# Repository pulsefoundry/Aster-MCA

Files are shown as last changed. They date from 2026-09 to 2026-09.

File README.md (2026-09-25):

# Aster MCA

[简体中文](README.zh-CN.md)

Aster MCA is a compact, USB-powered 4096-channel pulse-height analyzer for
already-amplified detector signals. It combines a 12-bit 10 MSPS ADC, a Gowin
GW1N-4 FPGA, and a CH347T USB/JTAG/UART bridge on one 90 mm × 70 mm four-layer
board.

> **Prototype status:** revision 0.1 has acquired a repeatable Cs-137 spectrum
> from an amplified NaI(Tl)/PMT probe, but the published as-built hardware has
> three mandatory assembly notes. Do not order or assemble the v0.1 production
> package unchanged. See [Hardware errata](docs/hardware-errata-v0.1.md).

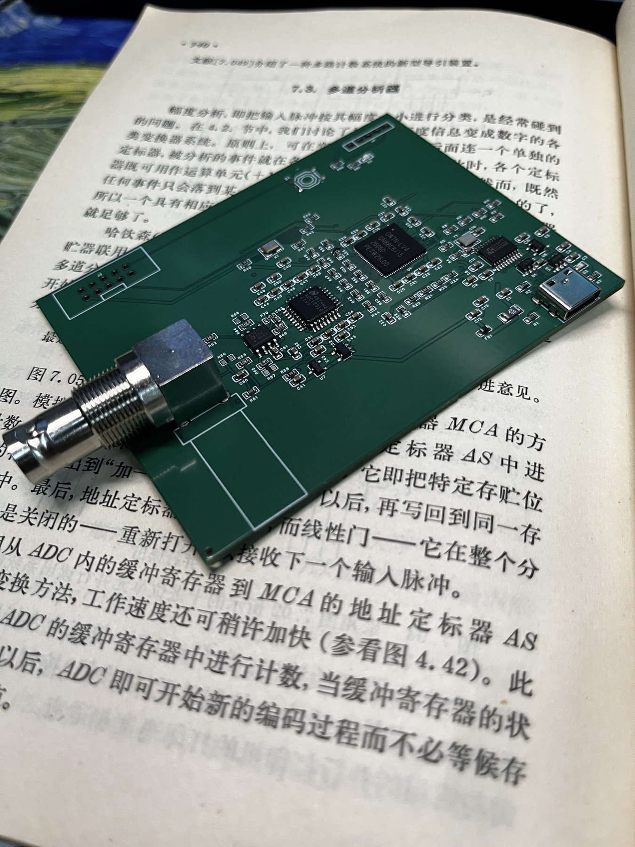
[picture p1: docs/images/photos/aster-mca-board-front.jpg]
Assembled Aster MCA v0.1 prototype board


*Assembled and physically validated v0.1 prototype.*

## What works

- ADC12010 parallel capture at 10 MSPS.
- FPGA baseline tracking, threshold detection, peak-height extraction, pulse
  rejection, saturation recovery, and a 4096 × 32-bit histogram.
- USB communication on macOS through the on-board CH347T and libusb; no serial
  driver or external programmer is required.
- Volatile SRAM configuration over the same USB-C connector.
- Live diagnostics for ADC min/max/baseline, triggers, accepted/rejected and
  saturated events, histogram drops, live samples, and UART errors.
- Repeatable source-versus-background separation on the first repaired boards.

The current physically validated firmware is **v1.9**. It keeps the proven v1.3
MCA algorithm but moves all 12 ADC inputs into dedicated falling-edge IOLOGIC
registers, followed by a full-cycle fabric pipeline stage. Two independently
placed images now produce matching Cs-137 spectra. FPGA configuration is
volatile and must be reloaded after power loss.

## Aster MCA v2.0 concept

The repository also contains a routed, explicitly unreleased
[v2.0 high-performance concept](hardware/rev2.0-preliminary/README.md): a
16-bit 40 MSPS ADS5560, Intel MAX 10 FPGA, directly soldered RP2350 host module,
and three fixed analogue ranges of approximately 0.5x, 5x and 25x. The current
r8 CAD passes ERC, DRC and an independent 489-pin network audit, and its THS4551
front end has reproducible analogue simulations.

v2.0 has no FPGA firmware or physical prototype yet. Its manufacturing files
are published for review and quotation only and must not be treated as a
production release.

## Prototype photographs

| Powered bench prototype | Second PCB during assembly and inspection |
| --- | --- |
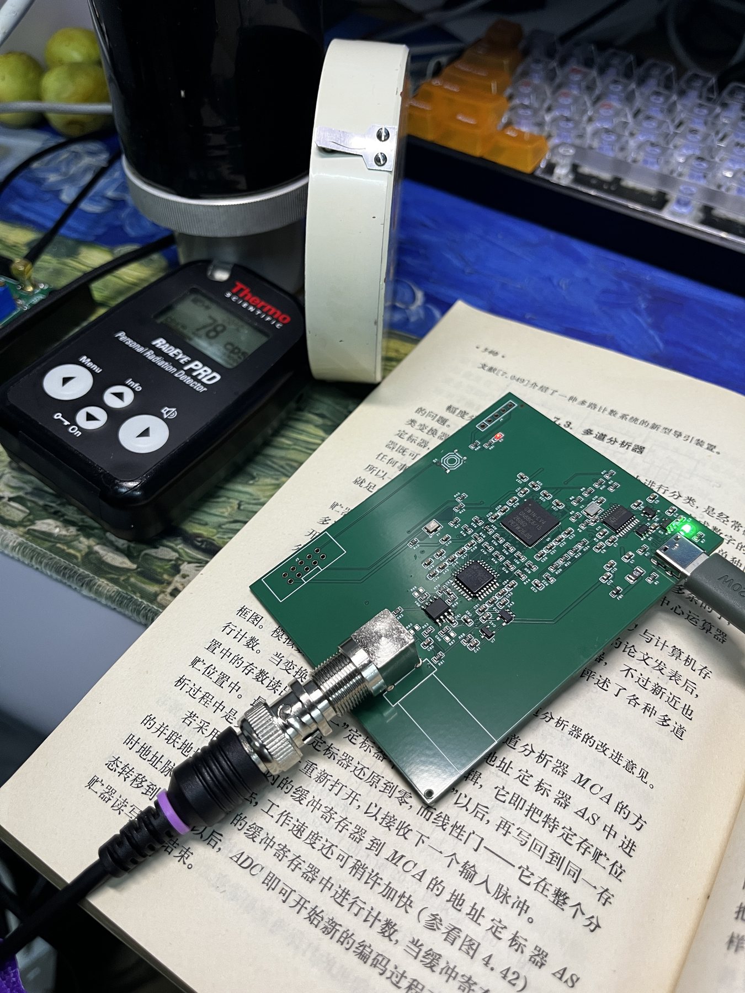
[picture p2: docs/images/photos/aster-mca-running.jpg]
Powered Aster MCA prototype
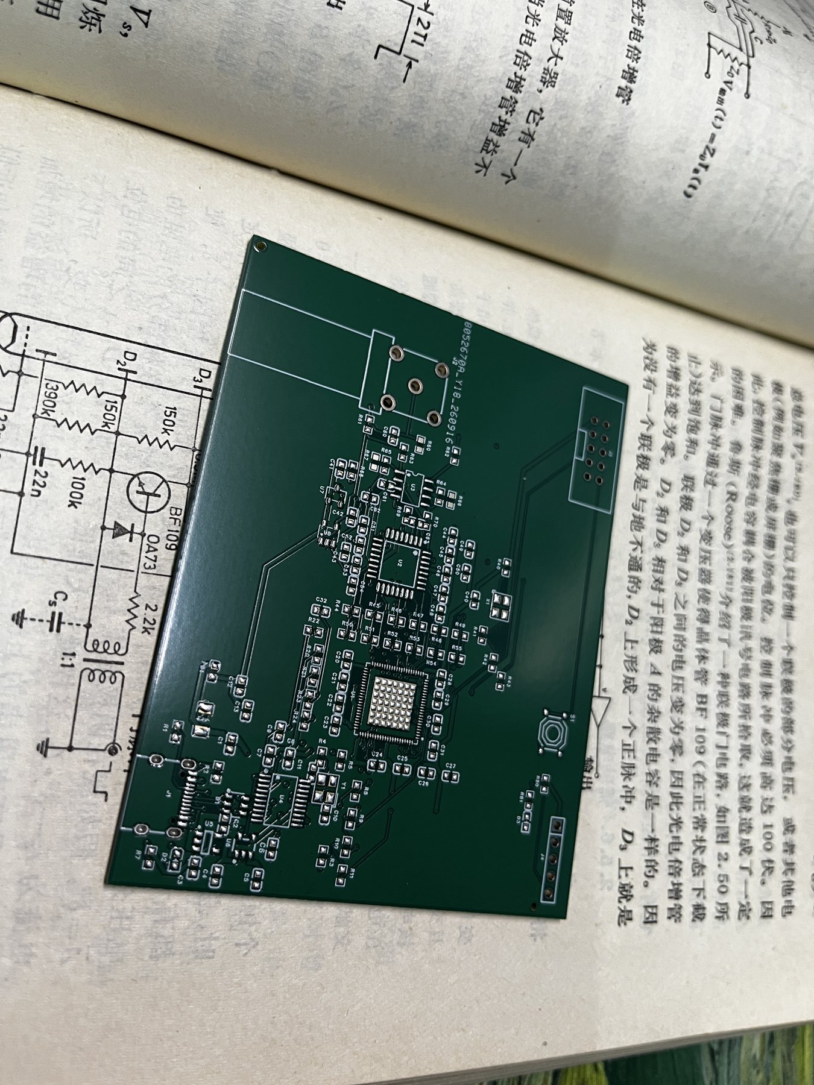
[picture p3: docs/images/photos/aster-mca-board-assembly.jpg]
Second Aster MCA PCB during assembly
|  |  |

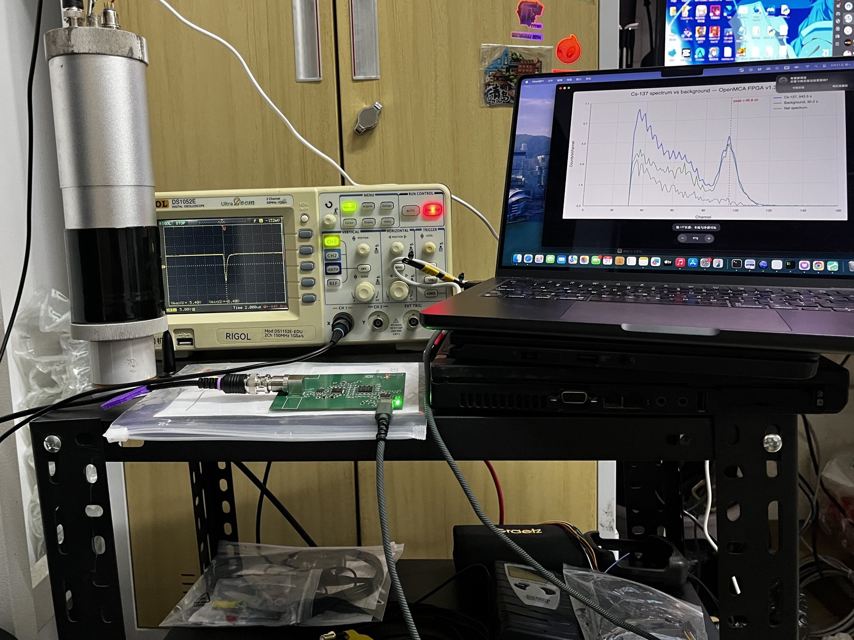
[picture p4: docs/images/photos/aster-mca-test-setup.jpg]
Initial Cs-137 bench setup


The full bench setup shows the amplified NaI(Tl)/PMT probe, oscilloscope,
Aster MCA prototype, and host computer during the initial Cs-137 validation.
The spectrum window in this photograph still carries the pre-release working
name used before the project was renamed Aster MCA.

## Measured prototype result

The initial validation used an amplified 1-inch NaI(Tl)/PMT probe and a Cs-137
check source. The analog stage was set to approximately ×3.33, the trigger
threshold was 32 ADC codes, and negative-going pulses were selected.

| Quantity | Result |
| --- | ---: |
| Source live time | 943.493 s |
| Source count rate | 252.19 counts/s |
| Background count rate | 77.72 counts/s |
| Net source rate | 174.47 counts/s |
| 662 keV peak position | about channel 95.8 |
| Preliminary FWHM | about 11.0 channels |
| Preliminary resolution | about 11.5% |
| Histogram drops | 0 |

These numbers describe one prototype setup, not a guaranteed instrument
specification. The energy estimate is based on a single known line, a short
background run, and a simple local-continuum subtraction. Raw CSV files are in
[`examples/cs137`](examples/cs137/).

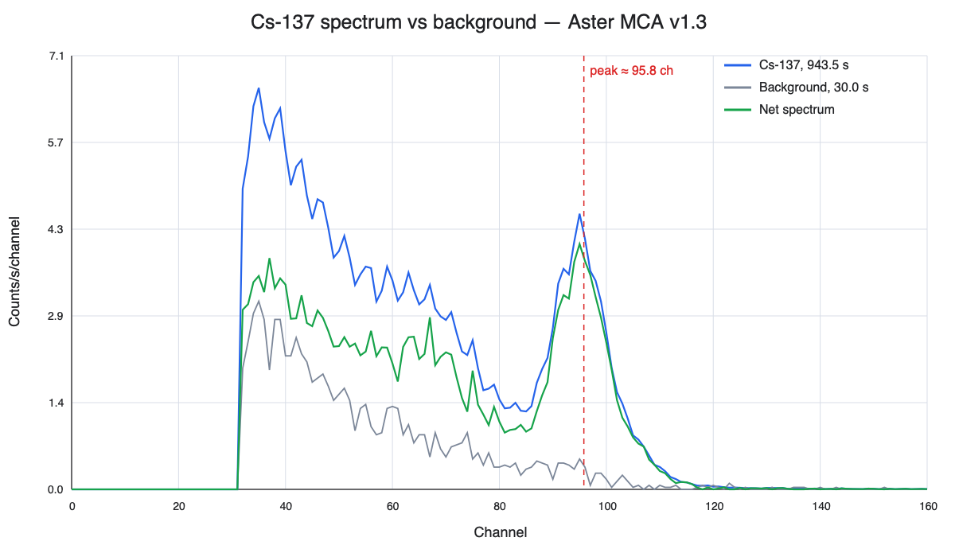
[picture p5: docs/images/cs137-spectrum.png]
Measured Cs-137 spectrum and background


## Analog gain options

R62/R63 are the matched 1.00 kohm `RG` pair and R64/R65 are the fitted matched
10.0 kohm `RF` pair. R66 and R67 are optional **parallel** feedback positions:
leave both open for nominal gain ×10, or fit the same value on both sides to
reduce the gain. The measured Cs-137 setup used 4.99 kohm, 0.1% at both R66 and
R67, giving `10k || 4.99k ≈ 3.33k` and nominal gain about ×3.33. Never populate
only one of the pair. See [Analog gain configuration](docs/gain-configuration.md)
for the formula, component roles, and calibration consequences.

## Signal path

```text
conditioned detector pulse
        │
        ▼
AC coupling and bias ──► AD8137 differential driver
        │
        ▼
ADC12010, 12 bit / 10 MSPS ──► GW1N-4 FPGA
        │                          │
        │                          ├─ baseline and peak extraction
        │                          └─ 4096-bin histogram
        ▼
CH347T USB UART/JTAG ──► macOS host utility
```

The BNC input is **low-voltage and signal-only**. The board has no detector
high-voltage supply, no high-voltage blocking network, and no charge-sensitive
preamplifier. Never connect a PMT bias line, a bare photomultiplier, or a
high-voltage detector cable directly to the input.

## Complete schematic

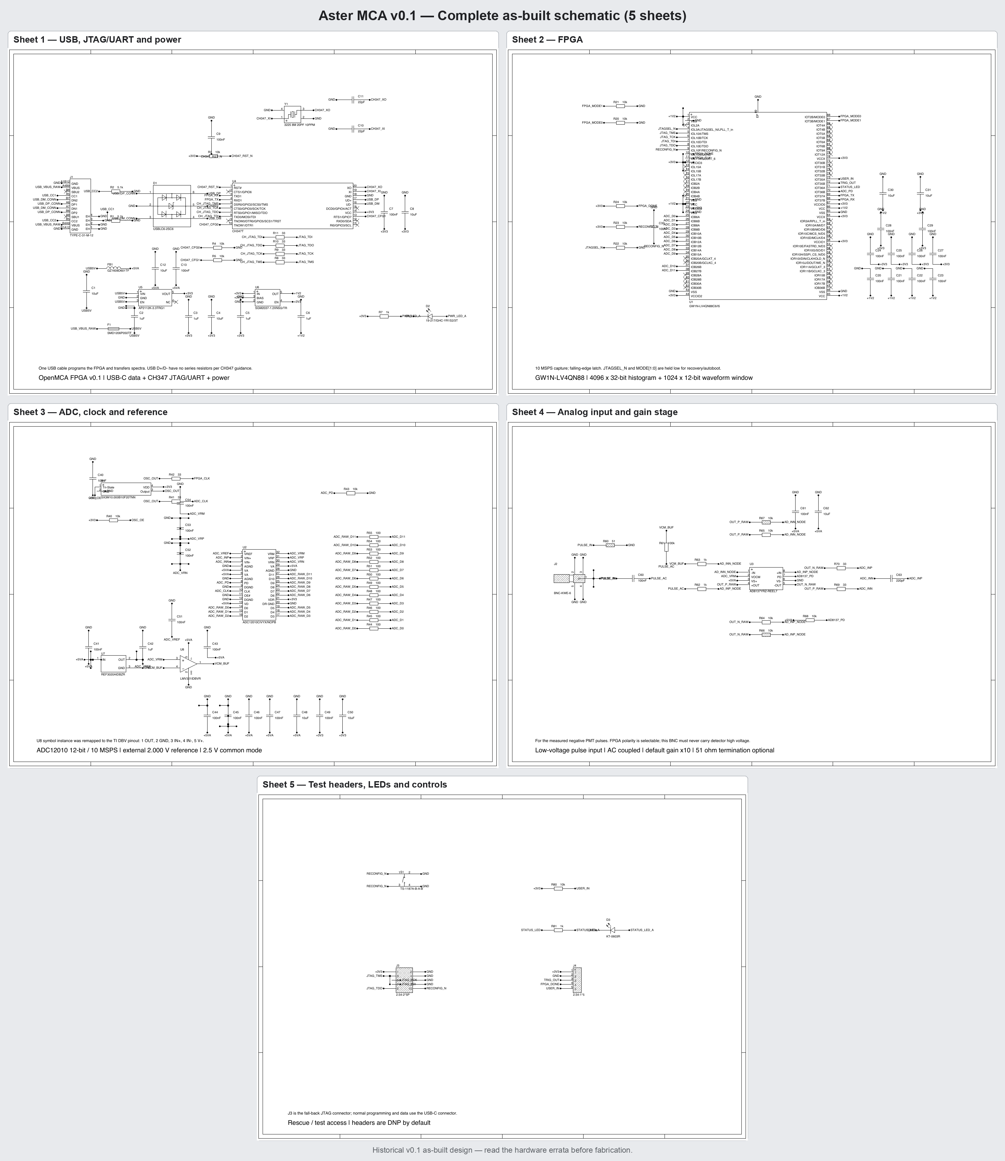
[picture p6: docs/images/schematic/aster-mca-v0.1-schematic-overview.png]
Complete five-sheet Aster MCA v0.1 schematic


The image above combines all five sheets of the as-built v0.1 schematic; click
it to open the original full-resolution PDF. It documents the manufactured
prototype and therefore includes the known U8, S1, and U6 assembly notes. Read
the [hardware errata](docs/hardware-errata-v0.1.md) before fabrication.

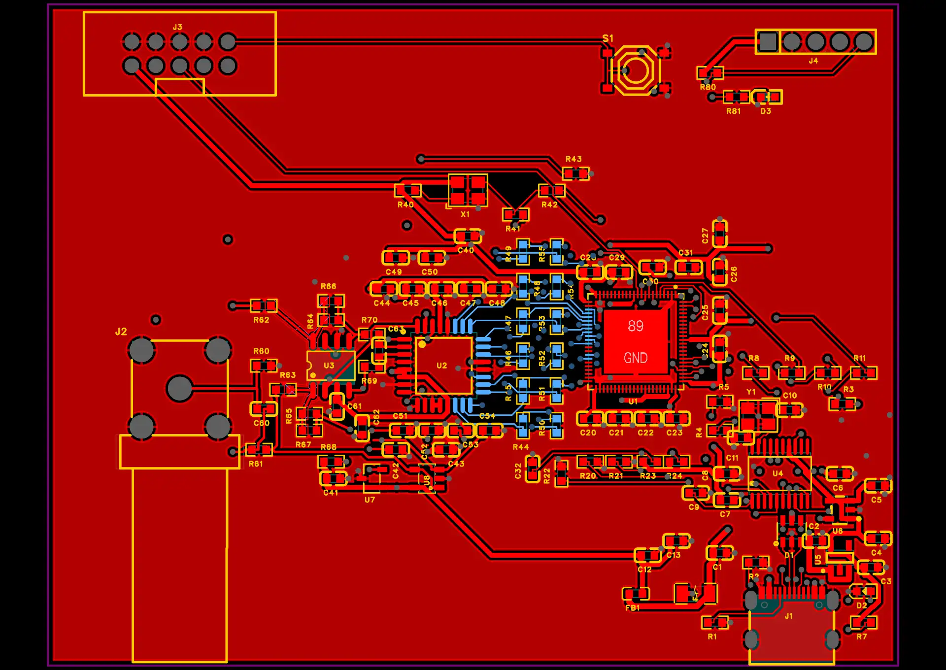
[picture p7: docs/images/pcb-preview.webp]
Aster MCA v0.1 PCB preview


## Repository layout

- `hardware/rev0.1-as-built/` — EasyEDA Pro source, Gerbers, BOM, CPL,
  schematic, netlist, and pin/net reference for the manufactured prototype.
- `firmware/mca-v1/` — synthesizable Verilog, constraints, simulations, host
  utility, tests, and validated v1.3 and v1.9 SRAM images.
- `docs/` — bring-up procedure, protocol, hardware errata, and validation
  notes.
- `examples/cs137/` — raw spectrum and background CSV files.

## Fabrication archive

The complete v0.1 as-built package is available as
[`Aster-MCA-v0.1-as-built-production.zip`](release/Aster-MCA-v0.1-as-built-production.zip).
It contains the native EasyEDA Pro project, Gerbers, BOM, CPL, schematic,
netlist, pin/net reference, assembly overrides, and hardware licence. This is
the manufactured prototype archive, not a corrected production release: read
the included notice and [v0.1 errata](docs/hardware-errata-v0.1.md) first.

## Quick start with an existing repaired board

Requirements on macOS:

```sh
brew install libusb openfpgaloader iverilog
```

Load the tested prebuilt image into FPGA SRAM:

```sh
cd firmware/mca-v1
openFPGALoader -c ch347_jtag --freq 1000000 -m \
  prebuilt/aster-mca-v1.9.fs
```

The original v1.3 image remains available as a fallback. See
[Algorithm development](docs/algorithm-development.en.md) for the ADC capture
fault, physical placement-seed test, and the rules for future algorithm A/B
comparisons.

Read the board and acquire a spectrum:

```sh
python3 astermca.py info
python3 astermca.py stats
python3 astermca.py acquire 600 --threshold 32 -o spectrum.csv
```

For a first power-up, follow [`docs/bring-up.md`](docs/bring-up.md) rather than
connecting a detector immediately.

## Build and test

The FPGA build uses Yosys, nextpnr-himbaechel, `gowin_pack`, Icarus Verilog,
and openFPGALoader. The easiest route is an OSS CAD Suite release with its
`bin` directory on `PATH`.

```sh
cd firmware/mca-v1
make sim
make host-test
make
make detect
make load-sram
```

You can instead pass an OSS CAD Suite binary directory explicitly:

```sh
make TOOLBIN=/absolute/path/to/oss-cad-suite/bin
```

## Hardware revision warning

Revision 0.1 is published for transparency and reproducibility, not as a
drop-in production release:

1. **U8:** the released BOM specifies `LMV321IDBVR`, but the PCB net map expects
   the pin order of `MCP6001T-I/OT`. Fit the plain MCP6001T-I/OT variant or
   apply the documented bypass. Do not fit MCP6001R or MCP6001U.
2. **S1:** leave the reset switch unpopulated. The footprint contact pairing
   can hold `RECONFIG_N` low on the assembled board.
3. **U6:** the originally specified `SGM2037-1.2XN5G/TR` remains recommended
   for a new build. The substitute `AP2112K-1.2` was later verified to start
   successfully without added output capacitance. Extra parallel output
   capacitance is not normally required; consider it only if oscilloscope
   measurements confirm that an excessively fast +1V2 rise causes FPGA
   configuration or startup failure, then re-check regulator stability,
   overshoot, and repeatable FPGA configuration.

Read the full [v0.1 errata and recovery procedure](docs/hardware-errata-v0.1.md)
before using the fabrication files.

## Contributing

Bug reports, measurements from other detector/front-end combinations, host
support for additional operating systems, HDL review, and a corrected hardware
revision are welcome. See [CONTRIBUTING.md](CONTRIBUTING.md).

## AI-assisted development

The FPGA firmware, HDL tests, Python host utility, and parts of the technical
documentation were developed with assistance from OpenAI Codex/ChatGPT. The
release was subsequently checked by simulation, synthesis/place-and-route,
timing analysis, and operation on the physical prototype. See the full
[AI development disclosure](AI-DISCLOSURE.md).

## License

Hardware design files are licensed under CERN-OHL-P-2.0. Firmware, host
software, documentation, tests, images, and example data are licensed under
MIT. See [LICENSE.md](LICENSE.md) for the exact scope and full licence texts.

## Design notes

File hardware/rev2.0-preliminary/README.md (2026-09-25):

# Aster MCA v2.0 high-performance concept

This directory publishes the current **r8 engineering design** for a higher-
performance Aster MCA. It is a routed, auditable hardware concept, not a
released production design.

> **Do not order this revision as a finished instrument.** The schematic and
> PCB are internally consistent, but there is no MAX 10 firmware or physical
> prototype yet. Read [PRODUCTION-NOTICE.md](PRODUCTION-NOTICE.md) first.

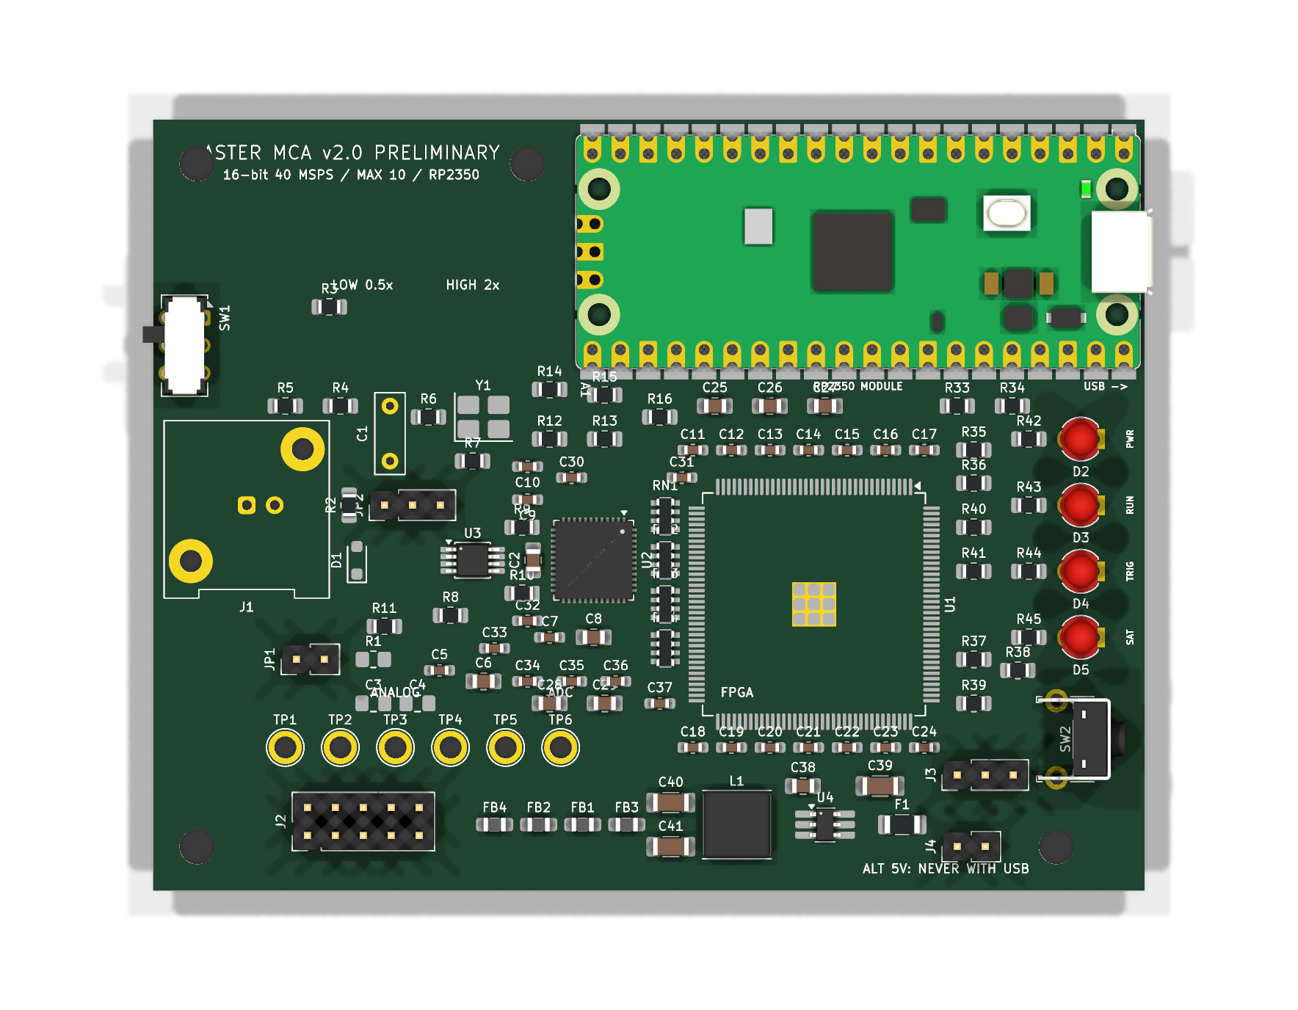
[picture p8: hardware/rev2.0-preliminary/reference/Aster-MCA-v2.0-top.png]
Aster MCA v2.0 r8 PCB top view


## Design direction

| Block | Current r8 choice |
| --- | --- |
| ADC | TI ADS5560, 16 bit, 40 MSPS, parallel CMOS output |
| FPGA | Intel MAX 10 10M16SAE144C8G, internal configuration flash, no external DDR |
| Host | Direct-soldered 52 mm x 21 mm RP2350/Pico 2-compatible castellated module |
| Analogue driver | TI THS4551 fully differential amplifier |
| Input ranges | Nominal 0.5x, 5x and 25x selected by a board-edge DP3T switch |
| Board | 90 mm x 70 mm, four layers, solid internal ground plane |
| User interface | Board-edge reset/reconfigure switch and four 3 mm through-hole LEDs |

The FPGA is intended to capture the complete 16-bit ADC bus and perform
triggering, baseline tracking, pulse-height/area extraction, pile-up handling,
histogramming and event buffering. The RP2350 module is intended to provide
USB, configuration, control and higher-level data transfer. Firmware for this
architecture has not yet been implemented.

## Three-range front end

The present resistor network provides three repeatable fixed ranges rather
than a dual potentiometer whose channel tracking and wiper noise would be hard
to calibrate:

| Range | Signal-side nominal gain | Intended use |
| --- | ---: | --- |
| Low | 0.5002x | Bring-up and occasional multi-volt detector pulses |
| Medium | 4.9665x | General spectroscopy range |
| High | 25.413x | Weak and low-energy pulses |

The reference-side gains are 0.5000x, 4.9751x and 25.413x. These are circuit
ratios for negligible detector source impedance, not energy-calibration
constants. Every assembled range requires pulse-injection and source
calibration. The 25x range is not presently qualified for multi-volt overload;
begin first power-up on 0.5x.

See [GAIN-OPTIMIZATION-r7.md](reference/GAIN-OPTIMIZATION-r7.md) for the exact
network and safety limits.

## Analogue simulation and r8 correction

The THS4551 front end was exercised with TI's PSpice macro-model. The original
10 ohm ADC isolation resistors showed a 9.74 dB simulated resonance near
35.5 MHz with the present 2.2 nF differential capacitor. r8 changes both
resistors to 22 ohm. The rerun produced approximately 1.56-1.65 MHz bandwidth,
less than 0.46 us simulated 1% settling, and no observed AC peaking in all
three ranges.

This model does not reproduce the ADS5560 switched-capacitor input, so the
result is a design check rather than a substitute for oscilloscope validation.
See [DAMPING-FIX-r8.md](reference/DAMPING-FIX-r8.md) and the reproducible files
under [`simulation/r7/`](simulation/r7/).

## Current verification status

Fresh checks against the r8 editable source on 2026-09-26 report:

- schematic ERC: 0 errors and 0 warnings;
- PCB DRC: 0 violations, 0 unconnected pads and 0 footprint errors;
- 111/111 manifest references present;
- all 489 numbered pad/net assignments match the independent manifest;
- critical FPGA/ADC clock, THS4551, AP63203, gain-switch and ADC-input networks
  pass the static audit;
- all four copper layers are present, with In1.Cu reserved as the solid ground
  plane.

These checks prove CAD consistency, not physical operation.

## Remaining release gates

1. Build and compile an exact `10M16SAE144C8G` Quartus project, proving package
   pin legality, ADC timing and the RP2350 interface.
2. Overlay the exact purchased 52 mm x 21 mm RP2350 clone on a 1:1 print and
   verify every castellated contact and USB overhang.
3. Verify the purchased JS203011AQN switch continuity and physical slider
   order before printing enclosure labels.
4. Bind every fitted BOM line to an exact purchasable part and recheck stock.
5. On a prototype, measure all rails, total USB current, ADC clock/data timing,
   front-end settling, overload recovery and range gain.
6. Repeat native EasyEDA/JLCPCB DRC, paste, rotation and 3D review before any
   assembly order.

## Files worth reviewing

- `source/Aster-MCA-v2.0.kicad_sch` and `.kicad_pcb` — current editable r8
  design and routing authority;
- `source/footprints/` — project-local production footprints;
- `reference/Aster-MCA-v2.0-schematic.pdf` — rendered schematic;
- `reference/parts-manifest.json` and `netlist-pin-map.csv` — independent
  connectivity references;
- `reference/quartus-pin-assignment-preliminary.csv` — preliminary MAX 10
  signal assignments, still requiring compilation;
- `production/quote-r8-current-source/` — quote-only Gerbers, BOM and CPL;
- `simulation/r7/` — analogue simulation and static-audit scripts and results.

The quote package is deliberately labelled **QUOTE ONLY**. It exists to study
cost and assembly options; it is not a production release.

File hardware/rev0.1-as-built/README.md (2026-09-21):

# Hardware revision 0.1 — as built

SPDX-License-Identifier: CERN-OHL-P-2.0

This directory is Covered Source under CERN-OHL-P-2.0. See the repository
root `LICENSE.md` and `LICENSES/CERN-OHL-P-2.0.txt`.

This directory archives the exact design lineage used for the first
manufactured Aster MCA boards. The native CAD archive still contains the
pre-publication `OpenMCA FPGA` working title; it is preserved unchanged inside
the evidence files so the manufactured revision remains traceable.

**Do not order this revision unchanged.** Apply the mandatory U8 replacement
leave S1 unpopulated, and fit the original SGM2037-1.2 at U6 as described in
[`../../docs/hardware-errata-v0.1.md`](../../docs/hardware-errata-v0.1.md).

## Contents

- `source/Aster-MCA-v0.1.epro2` — native EasyEDA Pro project archive (legacy
  project title retained internally).
- `production/Gerber.zip` — four-layer fabrication data.
- `production/BOM-native.tsv.utf16` — exact native UTF-16 BOM archive.
- `production/CPL-native.tsv.utf16` — exact native UTF-16 placement archive.
- `production/BOM-readable.tsv` and `CPL-readable.tsv` — UTF-8 copies for
  browser review and version-control inspection.
- `production/assembly-overrides.csv` — required deviations and DNP notes.
- `reference/Schematic.pdf` — five-page schematic export.
- `reference/Netlist.net` — exported netlist.
- `reference/Pin-net-reference.csv` — pin-to-net audit table.

The board is approximately 90 mm × 70 mm, four-layer FR-4, 1.6 mm thick. The
validated order used ENIG, 1 oz outer copper, 0.5 oz inner copper, and a stackup
with a thin outer-layer-to-reference-plane dielectric. USB differential
impedance was not verified by field solving, TDR, or an eye diagram; successful
enumeration on the tested boards is not a substitute for those measurements.

J2 is a hand-fitted BNC and is not part of the SMT placement file. J3/J4 are
optional headers. R60, R66, and R67 are configuration positions rather than
unconditionally fitted parts.

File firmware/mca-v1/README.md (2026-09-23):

# FPGA firmware v1.9

This directory contains the physically validated FPGA firmware for the Aster
MCA v0.1 board. It is designed for the Gowin `GW1N-LV4QN88C6/I5` and a 10 MHz
external ADC clock.

The normal load target writes volatile FPGA SRAM only. It does not modify the
device's non-volatile configuration memory.

This firmware, its HDL testbenches, and the Python host utility were developed
with assistance from OpenAI Codex/ChatGPT, then checked by simulation, complete
synthesis/place-and-route, timing analysis, and physical prototype operation.
See [`../../AI-DISCLOSURE.md`](../../AI-DISCLOSURE.md).

## Data path

- Capture all 12 ADC12010 offset-binary inputs on the falling edge using the
  Gowin IDDR cells physically located in IOLOGIC.
- Re-register the IDDR output after one complete 10 MHz clock period before it
  reaches the MCA engine, eliminating placement-dependent bus tearing.
- Track the quiet baseline, initialized at midscale (2048).
- Detect negative-going pulses by default with threshold and half-threshold
  release hysteresis.
- Freeze baseline tracking during large opposite-polarity excursions.
- Extract the peak amplitude after four quiet samples.
- Reject saturated or overlong events and wait 1 ms after saturation before
  accepting another event.
- Accumulate accepted peak heights in 4096 32-bit histogram bins.
- Report trigger, accepted, rejected, saturated, dropped, live-sample, and
  UART-error diagnostics.
- Drive a heartbeat/status LED and emit a 1 us trigger pulse on J4 pin 3.

## Build dependencies

- Yosys with Gowin support
- nextpnr-himbaechel
- `gowin_pack`
- Icarus Verilog (`iverilog` and `vvp`)
- Python 3
- openFPGALoader for CH347 JTAG access

An OSS CAD Suite distribution supplies the synthesis, place-and-route,
packing, and simulation tools. Put its `bin` directory on `PATH`, or pass it
to make:

```sh
make TOOLBIN=/absolute/path/to/oss-cad-suite/bin
```

## Test and build

```sh
make sim
make host-test
make
```

The final image is `build/aster-mca-v1.fs`. A physically validated copy is
checked in as `prebuilt/aster-mca-v1.9.fs`. The packer output requires the
included revision-ID/first-frame CRC correction, which the Makefile applies
with `tools/patch_gowin_id_crc.py`.

## Load through the on-board CH347T

Detect the FPGA:

```sh
make detect
```

Load the newly built image into SRAM:

```sh
make load-sram
```

Load the checked-in, physically validated v1.9 image directly:

```sh
openFPGALoader -c ch347_jtag --freq 1000000 -m \
  prebuilt/aster-mca-v1.9.fs
```

The original v1.3 image remains available as a fallback:

```sh
openFPGALoader -c ch347_jtag --freq 1000000 -m \
  prebuilt/aster-mca-v1.3.fs
```

The v1.9 image was tested with two independently placed-and-routed builds. Both
used 12 IOLOGIC input cells and produced matching 30-second Cs-137 spectra.
See [`../../docs/algorithm-development.en.md`](../../docs/algorithm-development.en.md).

After a power cycle, load the image again.

## Host utility

`astermca.py` uses libusb to access the CH347T UART bulk endpoints directly.
The tested host is macOS with Homebrew libusb:

```sh
brew install libusb
python3 astermca.py info
python3 astermca.py stats
python3 astermca.py threshold 32
python3 astermca.py polarity negative
python3 astermca.py acquire 600 -o spectrum.csv
```

The CSV output contains `channel,counts`. `acquire` clears the previous
histogram, waits, reads the FPGA live-time statistics, downloads all 4096
bins, and saves them. Histogram transfer pauses event processing briefly;
use the reported FPGA live time rather than wall-clock time for precise rates.

## Protocol

See [`../../docs/protocol.md`](../../docs/protocol.md).

## Diagnostic images

The `aster-mca-adc-pulldown.cst` and `top_adc_pd_high.v` targets are bring-up
diagnostics, not the production image. They distinguish an actively driven
ADC bus from a tri-stated bus. Do not leave them loaded for detector use.

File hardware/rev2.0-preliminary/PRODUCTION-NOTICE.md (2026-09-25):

# Production status: hold

The editable source is the **r8 engineering revision** with nominal 0.5x, 5x
and 25x analogue ranges and 22 ohm THS4551-to-ADC isolation resistors. It
passes schematic ERC, PCB DRC and the independent PCB/manifest network audit.
It has not been built and has no matching MAX 10 firmware.

Files under `production/quote-r8-current-source/` are for quotation only. Do
not authorize an FPGA/ADC assembly order until all of the following are true:

1. the exact `10M16SAE144C8G` project passes Quartus pin-legality, timing and
   configuration checks;
2. the actual 52 mm x 21 mm RP2350 clone passes a 1:1 footprint and USB-overhang
   check;
3. the purchased DP3T switch's contact map and slider order are confirmed;
4. every fitted BOM line is bound to the exact manufacturer part and verified
   stock source;
5. customer-supplied or externally purchased FPGA/ADC parts have an assembly
   and inspection route appropriate for their fine-pitch exposed-pad packages;
6. the final native EasyEDA/JLCPCB job passes DRC, paste, rotation and 3D review.

The current CAD audit covers 111 footprints and 489 numbered pin/net
assignments. It does not prove ADC capture timing, USB power margin, real ADC
input stability, overload recovery or detector performance. Those require the
first physical prototype.

The older `candidate-r3` and `candidate-r4` archives are historical layout
milestones with superseded gain values. They are not r8 production packages.

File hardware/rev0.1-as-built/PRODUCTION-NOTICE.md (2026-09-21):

# Read this before fabrication

This archive preserves the exact Aster MCA v0.1 design lineage used to
manufacture the first prototype boards. It is provided for reproducibility
and review, **not as an error-free drop-in production release**.

Before assembling a board:

1. fit `MCP6001T-I/OT` at U8 instead of the BOM-listed `LMV321IDBVR`;
2. leave S1 unpopulated;
3. fit the originally specified `SGM2037-1.2XN5G/TR` at U6 for a new build;
   `AP2112K-1.2` was tested to start without extra capacitance. Consider adding
   a parallel output capacitor only after measurements prove an overly fast
   +1V2 rise is causing FPGA startup failure;
4. read `hardware-errata-v0.1.md` and `assembly-overrides.csv` in full.

R66 and R67 are matched parallel feedback options. Leave both DNP for nominal
gain ×10, or fit the same value at both positions. The validated detector setup
used 4.99 kohm, 0.1% at both positions for nominal gain about ×3.33. Read the
included analog gain configuration guide; never populate only one side.

The BNC input is for an already-amplified, conditioned, low-voltage detector
signal. It is not a PMT high-voltage input and contains no detector bias supply
or charge-sensitive preamplifier.

## Package contents

- native EasyEDA Pro project;
- Gerber fabrication archive;
- native and human-readable BOM/CPL files;
- assembly overrides;
- schematic, netlist, and pin/net reference;
- hardware errata and CERN-OHL-P-2.0 licence text.

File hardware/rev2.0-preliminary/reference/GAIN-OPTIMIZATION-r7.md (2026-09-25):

# Aster MCA v2.0 three-range front end r7

Status: engineering revision for bench validation. This is not yet a released
production package, and `production/candidate-r4/` remains unchanged.

## Why three fixed ranges

The detector produces mostly tens-to-hundreds of millivolts pulses, with rare
background pulses reaching several volts. A continuous potentiometer would be
convenient, but two accurately related resistance arms are required around the
fully differential amplifier. An ordinary dual potentiometer adds tracking
error, wiper noise, temperature drift and an easily disturbed calibration.

r7 therefore uses one DP3T switch and three pairs of fixed 0.1% resistors. It
provides a wide safety range, a general-purpose range and a high-sensitivity
range while remaining reproducible and calibratable.

## Fitted values and nominal gains

R7 and R8 are 2.00 kohm feedback resistors. R2, 78.7 ohm, is shared by all
signal-side ranges. With negligible detector source impedance:

| Range | Signal-side path | Signal gain | Reference-side path | Reference gain | Arm mismatch |
|---|---:|---:|---:|---:|---:|
| 0.5x | R2 + R5 = 78.7 + 3920 ohm | 0.50016x | R6 = 4000 ohm | 0.50000x | 0.0325% |
| 5x | R2 + R46 = 78.7 + 324 ohm | 4.96648x | R47 = 402 ohm | 4.97512x | 0.174% |
| 25x | R2 + R3 = 78.7 + 0 ohm | 25.41296x | R4 = 78.7 ohm | 25.41296x | nominally 0% |

These are circuit ratios, not energy calibration constants. Detector output
impedance, resistor tolerance, amplifier error, ADC reference and digital pulse
processing all affect the measured channel position. Each range needs its own
energy calibration.

## Switch and net map

SW1 is C&K/Littelfuse JS203011AQN, a right-angle, non-shorting DP3T slide
switch. Its two poles select both differential input arms together:

| SW1 pin | Net | Function |
|---:|---|---|
| 1 | GAIN_H_SIG | 25x signal path |
| 2 | GAIN_M_SIG | 5x signal path |
| 3 | GAIN_SRC | signal pole common |
| 4 | GAIN_L_SIG | 0.5x signal path |
| 5 | GAIN_H_GND | 25x reference path |
| 6 | GAIN_M_GND | 5x reference path |
| 7 | GND | reference pole common |
| 8 | GAIN_L_GND | 0.5x reference path |

The PCB labels the available ranges, but the left/middle/right slider-to-range
order must be confirmed with a continuity meter on the purchased switch before
enclosure labeling. Because the switch is non-shorting, stop acquisition before
changing range, then clear/restart the histogram after switching.

## Expected use

- Use 0.5x for the largest amplified PMT pulses and initial bring-up.
- Use 5x as the normal wide-dynamic-range spectroscopy setting.
- Use 25x for weak/low-energy pulses. Rare several-volt events will saturate in
  this range and should be reported as overflow or rejected, not interpreted as
  valid pulse heights.

The optional D1 input protector remains DNP. Its present one-diode footprint is
not a validated symmetric low-capacitance clamp for this bipolar pulse input.
The THS4551 datasheet specifies an absolute maximum differential input voltage
of +/-1 V and continuous input current of +/-10 mA. A multi-volt detector pulse
while the amplifier is saturated is therefore not a released operating
condition for the 25x range, even if the pulse is brief. Keep first bring-up on
0.5x, validate overload recovery with a current-limited pulse source, and add a
proper symmetric low-capacitance clamp/current limiter before advertising the
input as universally overvoltage tolerant.

## Release gates

1. Verify the purchased switch pin map and all three positions with power off.
2. Measure baseline, quiescent output and supply current in every range.
3. Inject calibrated negative pulses and measure gain, linearity, overshoot,
   settling and saturation recovery in every range.
4. Repeat with the intended PMT and with JP1 open. Fit the 50-ohm termination
   only if the detector output is specified to drive it.
5. Compare background and Cs-137 spectra between ranges, including overflow and
   pile-up statistics.
6. Only after those tests, copy r7 into a new production release directory and
   generate fresh Gerber, drill, BOM and placement files.

## Automated checks

- `ERC-r7-gain.report`: 0 violations.
- `DRC-r7-gain.report`: 0 violations, 0 unconnected pads and 0 schematic parity
  errors.

These checks prove CAD consistency, not analog performance or purchasability.

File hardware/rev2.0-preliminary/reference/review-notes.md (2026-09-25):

# Aster MCA v2.0 preliminary review notes

Date: 2026-09-24
Status: **not released for fabrication**

## What is materially improved over v0.1

- 16-bit/40 MSPS converter instead of 12-bit/10 MSPS.
- MAX 10 provides substantially more logic, block RAM, multipliers, and PLLs
  without requiring external DDR.
- The 52 mm x 21 mm Pico 2-compatible RP2350 host is soldered directly through
  its castellated edges.  This lowers height and removes 40 socket contacts,
  but module replacement now requires hot air or careful desoldering.
- True dual analog gain changes both halves of the differential driver together.
- The corrected nominal ranges are 0.4945× and 2.004×; the calculation includes
  the shared 100-ohm series resistor before the gain switch.
- The 0.4945× low range is chosen specifically so a roughly -2.7 V amplified PMT pulse
  does not automatically overdrive a ±1.78 V differential ADC input.
- Through-hole BNC, JTAG, edge-facing switches, jumpers, test points, and 3 mm
  status LEDs; ordinary passives are 0805/1206.

## Items deliberately not hidden

- A nominal 16-bit ADC is not a 16-effective-bit spectrometer.  Clock noise,
  front-end noise, grounding, input filtering, and pulse processing dominate.
- MAX 10 Quartus tools are not native macOS applications.  The hardware keeps a
  standard JTAG header; FPGA compilation/programming will need a supported
  Windows/Linux environment or a tested remote workflow.
- The final layout has been manually audited after routing. Critical analog,
  clock, OVR/SAT, power and configuration nets are covered by the independent
  r4 audit; final hardware behavior still requires first-article measurement.
- JLC/LCSC stock was not used to weaken the architecture.  U1/U2/U3 may need
  customer-supplied parts or hand placement if the assembly service has no stock.

## Power estimate to verify

The ADS5560 alone is specified around 674 mW at 40 MSPS.  MAX 10 dynamic current
depends strongly on the final design; Pico 2 and the 3.3 V converter also consume
from USB.  Do not assume every laptop port or cable will tolerate the final load.
Measure VBUS current and 3.3 V ripple with the FPGA configured and ADC clocked.

## r4 audit status

- KiCad PCB DRC: 0 violations, 0 unconnected pads and 0 parity errors.
- KiCad schematic ERC: 0 errors and 0 warnings.
- Independent audit: 50 passed, 0 warnings, 0 failures; 420 pin assignments
  checked against the manifest.
- The RP2350 module footprint was rebuilt from a clean stock Pico envelope: the
  accidental off-board keepouts and paste apertures were removed. It remains a
  hand-soldered module and still requires a 1:1 check against the purchased
  clone.
- ADC OVR feeds the FPGA only. The SAT indicator is now driven from a separate
  FPGA output so the LED cannot load the ADC status pin.

## Mechanical r2 snapshot (historical, 2026-09-25)

- A1 now uses the standard Pico common SMD castellated footprint.  The supplied
  module photograph matches the standard 40-pin order and the stated envelope
  is 52 mm x 21 mm.
- SW1 is a right-angle DPDT at the left wall; SW2 is a right-angle tactile
  switch at the right wall.  The rendered actuator directions point outward.
- D2-D5 are 3 mm diffused through-hole indicators in a right-side column.
- The top-right carrier mounting hole moved inward because the direct-soldered
  RP2350 module occupies that corner.
- Routing was deliberately reset.  `DRC-mechanical-r2.rpt` is a mechanical
  placement snapshot, not an electrical sign-off.
- The KiCad schematic and PCB were imported into the native EasyEDA Pro project
  `Aster-MCA-v2.0` and saved as checkpoint `preliminary-20260924`.  This proves
  editability only; exact LCSC/JLC footprint binding, native DRC, SMT origin
  review, and 3D inspection remain mandatory.

## Current r7 gain experiment

The live files in `source/` now use a top-edge JS203011AQN DP3T switch and
0.5x / 5x / 25x resistor ranges. This supersedes the r2 DPDT placement only in
the engineering source; `production/candidate-r4/` remains the preserved,
earlier two-range candidate. See `GAIN-OPTIMIZATION-r7.md` for the exact gain
ratios and required bench validation.

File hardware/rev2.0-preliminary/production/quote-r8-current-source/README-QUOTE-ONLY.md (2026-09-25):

# Aster MCA v2.0 r8 quotation package

This directory is for fabrication and assembly **quotation only**.  It is made
from the current r8 editable source, including R9 = R10 = 22 ohm.  It is not an
electrical production release and must not be submitted as a final order until
the MAX 10 Quartus compile and the remaining physical checks are complete.

## Which files to upload

- PCB quotation: `Aster-MCA-v2.0-r8-Gerbers.zip`
- Minimum factory assembly quotation:
  - `Aster-MCA-v2.0-r8-BOM-core-SMT.csv`
  - `Aster-MCA-v2.0-r8-CPL-core-SMT.csv`
- Full SMT quotation for comparison:
  - `Aster-MCA-v2.0-r8-BOM-all-SMT.csv`
  - `Aster-MCA-v2.0-r8-CPL-all-SMT.csv`

The core option contains 38 placements: every 0402/0603 part, the four 0603x4
resistor arrays, FPGA, ADC, FDA, buck regulator and 40 MHz oscillator.  The
remaining 0805/1206 and through-hole parts are left for hand assembly.

The all-SMT option contains 86 placements and leaves only the RP2350 module,
connectors, switches, LEDs, headers, jumpers and test points for hand assembly.

## Exact critical part bindings used for quotation

| Ref. | Manufacturer part | LCSC part |
|---|---|---|
| U1 | 10M16SAE144C8G | C1521931 |
| U2 | ADS5560IRGZT | C571255 |
| U3 | THS4551IDGKT | C2860660 |
| U4 | AP63203WU-7 | C780769 |
| Y1 | ASE-40.000MHZ-L-C-T | C1670009 |
| RN1-RN4 | RTA03-4D330JTP | C102663 |
| C2 | GCM1885C1H222JA16D, 2.2 nF C0G | C343869 |
| C38 | CL05B104KO5NNNC, 100 nF 0402 X7R | C1525 |
| Other 100 nF 0603 | CC0603KPX7R8BB104, 25 V X7R | C1853266 |

Do not accept an automatic substitute for U1, U2, U3, U4 or Y1.  A package
match by itself is not sufficient.

## Stock and price warning, checked 2026-09-25

The public LCSC pages showed approximately USD 78.61 each for U1 and USD 73.26
each for U2.  The U2 page reported out of stock; U1 availability was inconsistent
between the product and image pages.  Therefore an online assembly quote may be
blocked even though the CSV files import correctly.

At the public reference prices, U1 and U2 alone are about USD 303.74 for two
assembled boards, approximately CNY 2,039 at 6.7133 CNY/USD.  Adding U3, U4 and
Y1 raises the five major-part subtotal to about CNY 2,155, before PCB, passive
parts, setup, assembly, tax and shipping.  These figures are reference estimates,
not a JLCPCB checkout quote.

If the assembly system reports U1 or U2 unavailable, stop at quotation.  The
practical alternatives are customer-supplied parts or purchasing the exact parts
elsewhere and arranging a service that accepts consigned components; do not let
the website choose a similar device automatically.

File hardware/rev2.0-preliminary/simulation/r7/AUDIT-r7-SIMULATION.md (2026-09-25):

# Aster MCA v2.0 r7 — simulation and electrical audit

Date: 2026-09-25
Design under test: `source/Aster-MCA-v2.0.kicad_sch` and
`source/Aster-MCA-v2.0.kicad_pcb`
Overall status: **HOLD FOR ONE ANALOGUE VALUE CHANGE AND DIGITAL COMPILE**

## Executive result

The core analogue topology runs in simulation. The 0.5x, 5x and 25x selected
gain networks produce 0.5015x, 4.9688x and 25.3930x respectively, which agrees
with the resistor calculations. The current r7 CAD also passes a fresh ERC and
DRC, and an independent board-to-manifest comparison found no connectivity,
value, DNP or footprint-reference mismatch.

One actionable problem was found: with the presently fitted **R9 = R10 =
10 ohm** and C2 = 2.2 nF, the TI THS4551 model predicts sustained/growing
high-frequency ringing in the 0.5x range. The AC sweep shows the same mode as a
9.74 dB peak near 35.5 MHz. A value sweep shows that changing **R9 and R10 to
22 ohm** removes the simulated ringing and peaking while retaining about 1.65 MHz closed-
loop bandwidth and approximately 0.44 us 1% settling for the tested pulse.
This is a BOM/value-only change; the nets and PCB placement do not need to move.

This report does **not** claim that the complete instrument can already boot.
There is not yet an exact MAX 10 Quartus project/bitstream for v2, so FPGA pin
legality, timing closure, ADC capture and RP2350 communication remain release
gates.

## What was actually simulated

- KiCad-bundled ngspice 45.2 shared library on macOS;
- TI THS4551 official PSpice macro-model from SBOMB92B;
- 5 V THS4551 supply and 1.5 V ADS5560 VCM drive;
- the actual r7 input and feedback resistor values;
- R9/R10 output isolation, C2 differential capacitor and a high-impedance ADC
  load;
- scaled negative small-signal pulses for all three ranges;
- a 2 us, -2.7 V source pulse for overload exploration;
- 10 Hz to 100 MHz AC sweeps;
- an R9/R10 damping sweep from 10 ohm to 100 ohm.

The TI model contains three PSpice `TABLE` controlled sources and PSpice switch
threshold syntax that the KiCad ngspice build cannot use directly. The included
preparation script translates each table to a behavioural PWL source with the
same data points and converts ON/OFF thresholds to the equivalent centre and
hysteresis values. No model electrical data points are altered.

The ADS5560 is represented by the board's external 2.2 nF differential
capacitor and a high-impedance differential load. Its internal sampled input,
aperture behaviour, code quantisation and kickback are not modeled. Therefore
the R9/R10 result is a strong design warning, not a substitute for the final
oscilloscope test on real hardware.

## Nominal small-signal results

Each range is driven with an input that should produce about 100 mV differential
output, avoiding intentional clipping.

| Range | Input step | Simulated gain | Baseline differential offset | -3 dB bandwidth | Peaking | Result |
|---|---:|---:|---:|---:|---:|---|
| 0.5x | -200 mV | 0.50154x | +0.567 mV | 3.71 MHz* | +9.74 dB at 35.5 MHz, sustained ringing | **Needs damping change** |
| 5x | -20 mV | 4.96881x | +6.087 mV | 3.85 MHz | 0 dB | Pass in model |
| 25x | -4 mV | 25.39299x | +18.588 mV | 3.08 MHz | 0 dB | Pass in model |

`*` The 0.5x response crosses -3 dB at about 3.71 MHz before rising into the
high-frequency ringing mode; that bandwidth number must not be read as a clean
single-pole response.

The simulated differential baseline offsets correspond to roughly 10, 111 and
338 ideal ADS5560 LSBs at a 3.6 Vpp full-scale span. They do not consume a
dangerous amount of ADC headroom, but each range needs its own baseline
subtraction and energy calibration.

The ADC polarity is intentionally inverted by the PCB connection: THS4551
`OUT+` goes to `ADC_INM`, while `OUT-` goes to `ADC_INP`. A negative PMT pulse
therefore moves the signed ADC differential code negative. Firmware must keep
that convention explicit instead of assuming positive-going peaks.

## R9/R10 damping sweep for the 0.5x range

All rows keep C2 = 2.2 nF and change both output-isolation resistors together.

| R9 = R10 | AC peaking | -3 dB bandwidth | Step overshoot | 1% settling | Assessment |
|---:|---:|---:|---:|---:|---|
| 10 ohm | 9.74 dB | 3.71 MHz before resonance | 9.67% plus ringing | Not settled before pulse end | Reject |
| 22 ohm | 0 dB | 1.65 MHz | 0.0005% | 0.44 us | **Recommended** |
| 33 ohm | 0 dB | 1.10 MHz | 0.027% | 0.66 us | Acceptable but slower |
| 47 ohm | 0 dB | 0.77 MHz | 0.31% | 0.89 us | Usable for slow pulses |
| 68 ohm | 0 dB | 0.53 MHz | 1.74% | Not within 1% before pulse end | Too slow here |
| 100 ohm | 0 dB | 0.36 MHz | 5.73% | Not within 1% before pulse end | Reject |

Recommendation: change the schematic/BOM values of R9 and R10 from 10 ohm to
22 ohm, then rerun ERC/DRC and regenerate manufacturing outputs. On the first
assembled board, verify 0.5x and 25x with a calibrated fast pulse while probing
both ADC inputs. If the real ADS5560 load differs significantly from the model,
33 ohm remains a conservative bench alternative.

## Large-pulse behaviour

For a -2.7 V detector pulse, the linear closed-loop demand is approximately
-1.35 V, -13.4 V and -68.6 V differential in the three ranges. Only 0.5x can
remain inside the ADS5560 nominal 3.6 Vpp input span.

| Range | Estimated source current through selected signal resistor | Overload run | Interpretation |
|---|---:|---|---|
| 0.5x | 0.675 mA | Completed; minimum ADC differential -1.356 V; residual 0.186 mV by 8–10 us | Expected to accept this pulse |
| 5x | 6.70 mA | TI macro-model stopped near the onset of deep saturation | Must saturate; recovery needs bench measurement |
| 25x | 34.3 mA | TI macro-model stopped near the onset of deep saturation | Must saturate; input-current protection risk |

The incomplete 5x/25x overload runs are a macro-model convergence failure in
the model's ideal internal switch, not evidence that the physical board cannot
power up. They also cannot be treated as recovery validation. The 25x estimated
current exceeds the THS4551 continuous-input absolute-maximum value of 10 mA.
Because the observed PMT occasionally produces multi-volt pulses, 25x must be
treated as a weak-signal range: begin on 0.5x, do not switch ranges during
acquisition, and reject/safely clamp large events before calling the input
universally protected. D1 remains DNP because its present single-diode footprint
is not a validated symmetric low-capacitance clamp.

## Static electrical and CAD audit

Fresh runs against the current source files:

- ERC: 0 errors, 0 warnings;
- DRC: 0 violations, 0 unconnected pads, 0 footprint errors;
- 111 of 111 manifest references found on the PCB;
- all 111 PCB footprints accounted for;
- all values and DNP states match the manifest;
- all 489 numbered pad/net assignments match the manifest;
- four copper layers confirmed;
- AP63203 FB, EN, VIN, GND, SW and BST nets rechecked;
- THS4551 eight-pin net map rechecked;
- DP3T pins 1–8 and all six selected gain-resistor branches rechecked;
- R9/R10/C2 analogue output-filter nets rechecked;
- C9/C10/R15/R16 clock interface nets rechecked;
- worst nominal two-arm resistor-ratio mismatch is 0.174% in the 5x range.

No accidental short, missing selected branch, reversed THS4551 pin, stale DPDT
pad or unmatched PCB/schematic net was found.

## What is not yet proven

1. **FPGA compile and timing:** compile the exact 10M16SAE144C8G project in
   Quartus with all package assignments and clock constraints. There is no v2
   bitstream yet.
2. **ADC capture:** verify 40 MHz data timing, source-synchronous CLKOUT capture,
   signed code polarity and overflow handling in hardware.
3. **Real ADC load stability:** repeat the R9/R10 damping test on an assembled
   board. The simulation does not include ADS5560 internal sampling kickback.
4. **Power integrity:** the AP63203 static pin map is correct, but no vendor
   switcher transient model was included. Measure 3V3_RAW, 3V3_D, 3V3_A,
   3V3_FPGA_A, 5VA and supply current during FPGA configuration and ADC running.
5. **Physical switch order:** the C&K DP3T contact topology is accounted for,
   but verify the purchased part's slider positions with a continuity meter
   before printing enclosure labels.
6. **RP2350 clone fit:** retain the existing physical overlay/mechanical gate
   for the exact 52 mm x 21 mm clone.

## Release decision

The design is electrically coherent and the analogue core is viable, but r7
should not be promoted to a production package unchanged. The minimum next step
is:

1. change R9 and R10 to 22 ohm;
2. rerun this simulation plus ERC/DRC;
3. build and compile the exact MAX 10 firmware project;
4. bench-check all three ranges, especially 0.5x damping and 25x overload
   recovery/protection.

After those gates, the board has a credible path to a working instrument.

## Reproduction

Run the analogue tests (the model is fetched directly from TI if needed):

```sh
cd simulation/r7
python3 run_simulations.py --fetch-model
```

Run the board/manifest audit with KiCad's bundled Python:

```sh
/Applications/KiCad/KiCad.app/Contents/Frameworks/Python.framework/Versions/3.9/bin/python3.9 audit_static.py
```

Generated summaries and figures:

- `results/summary.json`
- `results/summary.csv`
- `results/static-audit.json`
- `results/ERC-current-r7.rpt`
- `results/DRC-current-r7.rpt`
- `plots/small-signal-transient.svg`
- `plots/minus-2p7v-overload.svg`
- `plots/low-range-output-damping-sweep.svg`

## Primary references

- TI, THS4551 datasheet: <https://www.ti.com/lit/ds/symlink/ths4551.pdf>
- TI, THS4551 product/model page: <https://www.ti.com/product/THS4551>
- TI, ADS5560 datasheet: <https://www.ti.com/lit/ds/symlink/ads5560.pdf>
- Diodes Incorporated, AP63203 datasheet:
  <https://www.diodes.com/assets/Datasheets/AP63200-AP63201-AP63203-AP63205.pdf>

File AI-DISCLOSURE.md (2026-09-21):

# AI-assisted development disclosure

The Aster MCA FPGA firmware, HDL testbenches, Python host utility, and parts of
the technical documentation were written and refined with assistance from
OpenAI Codex/ChatGPT.

AI-generated or AI-suggested material was not treated as independent evidence
that the instrument worked. The released firmware was checked with HDL
simulation, host-side protocol tests, complete synthesis and place-and-route,
timing analysis, and operation on the physical prototype. Detector connection,
bench measurements, source placement, hardware rework, and final acceptance
were performed by the human project owner.

Known design mistakes and prototype repairs are documented openly in
`docs/hardware-errata-v0.1.md`. Contributors should review AI-assisted changes
with the same care as any other untrusted contribution and should distinguish
simulation, inspection, and physical measurement in future reports.

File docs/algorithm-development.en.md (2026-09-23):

# FPGA algorithm and ADC-capture development

[简体中文](algorithm-development.md)

## Current conclusion

**v1.9 is the current physically validated firmware.** It keeps the baseline,
trigger, peak-height, and 4096-bin histogram algorithm from v1.3 and changes
only the ADC input path:

```text
parallel ADC bus
      |
      +-- 12 IOLOGIC IDDR cells, falling-edge capture
      |
      +-- one rising-edge fabric register, full-cycle timing margin
                |
                +-- v1.3 MCA engine
```

The extra register adds a fixed 100 ns latency at 10 MHz. It does not alter
pulse height or count rate.

## Why capture timing had to be fixed first

The original v1.3 design captured the 12-bit bus on the falling edge with
ordinary fabric registers. Their placement and input-routing delay were left to
place-and-route, without a robust input timing relationship.

An exact source rebuild was byte-for-byte identical to the checked-in v1.3
image. Re-running only place-and-route with seed 1, however, changed a 30-second
run from roughly 9,000 triggers and 1,500 rejected events to 53,364 triggers,
46,437 rejected events, and 1,737 saturated events. Baseline also moved from
about 2034 to 2106. Therefore several earlier apparent algorithm effects were
confounded by placement-dependent ADC bus tearing.

## Two-stage repair

1. **v1.8** placed one Gowin `IDDR` on every ADC pin. Baseline became correct,
   but IDDR Q1 still crossed into same-edge MCA logic; seed 1 produced 37,687
   triggers and 30,645 rejections.
2. **v1.9** added a fabric register after IDDR, providing a complete 100 ns
   IOLOGIC-to-fabric cycle. The placement-seed-dependent false triggers vanished.

## Physical v1.9 A/B result

The same NaI(Tl)/PMT detector, Cs-137 position, 32-code threshold, and 30 seconds
of FPGA live time were used:

| Item | Default placement | Seed 1 placement |
| --- | ---: | ---: |
| Triggers | 9,258 | 9,177 |
| Accepted | 7,782 | 7,742 |
| Rejected | 1,476 | 1,435 |
| Saturated | 207 | 183 |
| Mean accepted rate | 259.282 cps | 257.955 cps |
| Local Cs-137 peak | channel 99 | channel 99 |
| Centroid, channels 85-114 | 99.57 | 99.26 |

The mean channels over 32-159 were 62.97 and 63.03. These differences are
consistent with short-run counting statistics rather than the catastrophic
placement sensitivity of the old capture path.

## Build result

| Resource or timing item | Default placement | Seed 1 |
| --- | ---: | ---: |
| LUT4 | 2,120 / 4,608 | 2,117 / 4,608 |
| DFF | 982 / 3,456 | 982 / 3,456 |
| BSRAM | 8 / 10 | 8 / 10 |
| IOLOGICI | 12 / 198 | 12 / 198 |
| Estimated maximum clock | 61.13 MHz | 55.06 MHz |
| Required clock | 10 MHz | 10 MHz |

## Treatment of earlier algorithm experiments

The v1.4 boxcar, v1.5 two-sample confirmation, v1.6 light confirmation, and
v1.7 baseline-rounding experiments were all physically exercised. Each build
also changed placement, so their spectrum differences can no longer be
attributed to the algorithm alone. They must not be published as recommended
images.

Future algorithm A/B tests must start from the v1.9 capture path, keep detector,
source, bias, gain, threshold, and FPGA live time fixed, and confirm the result
with at least two placement seeds. Trigger, accepted, rejected, saturated, and
dropped counters should be retained before comparing peak position and FWHM.

The next useful algorithm feature is a small triggered-waveform capture or
separate rejection-reason counters, followed by state-machine tuning based on
measured pulse shapes.

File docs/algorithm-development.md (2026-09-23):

# FPGA 算法与采样链改进记录

[English](algorithm-development.en.md)

## 当前结论

**v1.9 是当前经过实板验证的版本。** 它保留 v1.3 的基线、触发、峰值与
4096 道直方图算法，只修正 ADC 输入采样链：

```text
ADC 并行数据
      │
      ├── 12 个 IOLOGIC IDDR，下降沿采样
      │
      └── 一级上升沿布线区寄存器（整周期裕量）
                │
                └── v1.3 MCA 引擎
```

这会增加一个 10 MHz 周期（100 ns）的固定延迟，但不会改变脉冲峰高或
计数率。

## 为什么先修采样，而不是继续改算法

v1.3 原来用普通 FPGA 寄存器在 ADC 时钟下降沿直接采样 12 位并行总线。
这些寄存器的位置和引脚到寄存器的延迟由布局布线决定，且输入时序
没有受到可靠约束。

直接证据是：重建的 v1.3 与仓库预编译镜像逐字节一致；但同一份综合网表
仅把 nextpnr seed 改为 1，30 秒运行就变为：

| 镜像 | 触发 | 接受 | 拒绝 | 饱和 |
| --- | ---: | ---: | ---: | ---: |
| v1.3 稳定布局 | 约 9,000 | 约 7,800 | 约 1,500 | 约 200 |
| v1.3，仅 seed=1 | 53,364 | 6,927 | 46,437 | 1,737 |

基线也由约 2034 偏到 2106。这说明之前“改一行算法便改变谱形”的部分
结果，实际上被重新布局后的 ADC 总线撕裂混淆。

## 两步修复

1. **v1.8：** 用 12 个 Gowin `IDDR` 把下降沿采样放进每个引脚的 IOLOGIC。
   基线恢复正常，但 IDDR Q1 与 MCA 引擎在同一上升沿交接，seed=1
   仍有 37,687 次触发和 30,645 次拒绝。
2. **v1.9：** 在 IDDR 后再加一级布线区寄存器，给 IOLOGIC 到算法一个
   完整的 100 ns 周期。两个布局 seed 的异常触发消失。

## v1.9 实板 A/B 结果

使用同一 NaI(Tl)/PMT 探头、Cs-137 源位置、32 ADC 道阈值和 30 秒 FPGA
有效时间：

| 项目 | 默认布局 | seed=1 布局 |
| --- | ---: | ---: |
| 触发 | 9,258 | 9,177 |
| 接受 | 7,782 | 7,742 |
| 拒绝 | 1,476 | 1,435 |
| 饱和 | 207 | 183 |
| 平均计数率 | 259.282 cps | 257.955 cps |
| Cs-137 局部峰位 | 99 道 | 99 道 |
| 85–114 道质心 | 99.57 | 99.26 |

32–159 道的平均道位分别为 62.97 和 63.03。差异符合 30 秒短谱的统计波动，
不再出现旧采样链随布局改变的灾难性假触发。

## 构建结果

| 项目 | 默认布局 | seed=1 |
| --- | ---: | ---: |
| LUT4 | 2,120 / 4,608 | 2,117 / 4,608 |
| DFF | 982 / 3,456 | 982 / 3,456 |
| BSRAM | 8 / 10 | 8 / 10 |
| IOLOGICI | 12 / 198 | 12 / 198 |
| 布局布线估计最高时钟 | 61.13 MHz | 55.06 MHz |
| 实际约束时钟 | 10 MHz | 10 MHz |

## 旧算法实验的处理

v1.4 四点滑动平均、v1.5 两点触发确认、v1.6 轻量确认和 v1.7 基线舍入
都曾在实板上试验。它们当时每次都重新布局布线，因而谱形差异不能再
单独归因于算法。这些版本不应作为推荐镜像发布。

今后任何算法 A/B 必须：

- 从 v1.9 采样链开始；
- 保持探头、源、高压、增益、阈值和 FPGA 有效时间一致；
- 至少用两个布局 seed 验证结论不依赖布局；
- 先保存触发、接受、拒绝、饱和和丢失计数，再比较峰位与 FWHM。

下一步应先加入小型触发波形捕获或细分拒绝原因计数，再优化触发状态机。

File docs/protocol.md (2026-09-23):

# USB/UART protocol

The FPGA UART is 1,000,000 baud, 8 data bits, no parity, and one stop bit. The
10 MHz FPGA clock gives exactly ten FPGA clocks per UART bit. The on-board
CH347T exposes this UART through USB bulk endpoints; the reference host utility
uses libusb directly.

## Commands

Commands are a single ASCII byte unless an argument is listed.

| Command | Argument | Meaning |
| --- | --- | --- |
| `I` | none | Return firmware and acquisition capabilities. |
| `S` | none | Return current ADC state and statistics. |
| `H` | none | Pause acquisition and return all 4096 histogram bins. |
| `C` | none | Clear the histogram and statistics. |
| `T` | little-endian uint16 | Set threshold; values below 4 are clamped to 4. |
| `P` | uint8 | Set polarity: 0 = rising code, 1 = falling code. |

## Response frame

Every response has this structure:

1. four-byte ASCII magic `MCA1`;
2. one-byte response type;
3. one-byte status (`0` means success);
4. little-endian uint16 payload length;
5. payload;
6. little-endian CRC-16/CCITT-FALSE over the header and payload.

CRC parameters are polynomial `0x1021`, initial value `0xffff`, no reflection,
and no final XOR.

Histogram values are little-endian uint32 values in channel order. The
histogram transfer pauses event processing so the host cannot read a bin while
the FPGA is updating it. Rate calculations should use the 64-bit live-sample
counter returned by `S`, divided by 10,000,000 samples/s.

The Python implementation in `astermca.py` is the executable protocol
reference. `tb_protocol.v` and `test_astermca.py` cover framing and CRC handling.

## INFO feature byte

The fourth byte of the 16-byte `I` payload is a feature bitmap:

| Bit | Meaning |
| ---: | --- |
| 0 | Peak-height histogram is implemented. |
| 1 | Triggering and peak extraction use a four-sample boxcar average. |
| 2 | A trigger requires two consecutive above-threshold samples. |
| 3 | Baseline IIR uses symmetric signed rounding. |
| 4 | ADC inputs use falling-edge IOLOGIC capture plus a fabric pipeline. |

Firmware v1.3 reports `0x01`; firmware v1.9 reports `0x11`. Bits 1 through 3
were assigned to development experiments and remain reserved. Unknown set bits
must be ignored by compatible host software.

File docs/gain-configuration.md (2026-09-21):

# Analog gain configuration

The AD8137 stage converts the AC-coupled single-ended detector pulse into the
differential signal used by the ADC. Its external matched resistor networks set
the nominal differential closed-loop gain. Analog Devices defines the matched
network gain as approximately `RF / RG`.

## Relevant positions

| Positions | Fitted value in the archived BOM | Function |
| --- | ---: | --- |
| R60 | DNP | Optional BNC input termination; changes source loading, not the AD8137 feedback ratio. |
| R61 | 100 kohm | DC bias return from the AC-coupled input to `VCM_BUF`; not a gain adjustment. |
| R62, R63 | 1.00 kohm, matched | The two `RG` arms. |
| R64, R65 | 10.0 kohm, matched | The permanently fitted `RF` pair. |
| R66, R67 | DNP by default | Optional resistors in parallel with R64 and R65 respectively. |
| R69, R70 | 33 ohm | ADC input isolation/settling resistors; not closed-loop gain adjustments. |

R66 and R67 are **parallel gain-option pads**, not series resistors and not two
independent controls. Fit both with the same value and tolerance, or leave both
unpopulated. Fitting only one side unbalances the differential driver.

With `R62 = R63 = RG = 1.00 kohm`, the nominal gain magnitude is:

```text
RF+ = R64 || R66
RF- = R65 || R67
Gain ≈ RF / RG, provided RF+ and RF- are matched
```

An unpopulated option pad is treated as infinite resistance.

| R66 and R67 population | Effective RF on each side | Nominal gain | Status |
| ---: | ---: | ---: | --- |
| DNP | 10.0 kohm | about ×10 | Archived BOM default; likely to clip the amplified PMT pulses used in validation. |
| 10.0 kohm each | 5.00 kohm | about ×5 | Calculated example; not physically characterized. |
| 4.99 kohm, 0.1% each | 3.33 kohm | about ×3.33 | Physically validated with the amplified 1-inch NaI(Tl)/PMT probe and Cs-137 source. |

Reducing the gain increases the detector-input amplitude that can be accepted
before ADC clipping, but it also reduces ADC codes per volt and therefore makes
small pulses use fewer channels. Every population change requires a new energy
calibration and a check of baseline, pulse polarity, clipping, and noise.

The values above describe the AD8137 feedback ratio, not a guaranteed end-to-end
calibration. Source impedance, optional R60 termination, coupling components,
ADC range, and detector electronics also affect the measured system response.

Reference: [Analog Devices AD8137 data sheet](https://www.analog.com/media/en/technical-documentation/data-sheets/ad8137.pdf).

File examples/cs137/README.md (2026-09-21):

# Cs-137 example data

- `source-943s.csv` — 943.493 s source acquisition, 4096 bins.
- `background-30s.csv` — 30.017 s background acquisition, 4096 bins.

Both files contain two columns: `channel,counts`. The runs used firmware v1.3,
threshold 32, negative-going pulses, and analog gain near ×3.33. Normalize each
file by its FPGA live time before subtracting the background.

The corresponding plot and analysis caveats are in `docs/validation.md`.

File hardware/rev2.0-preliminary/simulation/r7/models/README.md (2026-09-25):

# THS4551 vendor model

The TI macro-model is not copied into this project. Download **THS4551 PSpice
Model, SBOMB92B.ZIP** from:

<https://www.ti.com/lit/zip/sbomb92>

Extract `ths4551.lib`, then run:

```sh
python3 ../run_simulations.py --model /path/to/ths4551.lib
```

Alternatively, `--fetch-model` retrieves the same archive directly from TI.
`prepare_ti_model.py` converts three PSpice `TABLE` sources to native ngspice
behavioural PWL sources with the same point pairs and normalizes switch model
threshold syntax. Generated vendor-derived files stay under `work/` and are not
part of the project sources.

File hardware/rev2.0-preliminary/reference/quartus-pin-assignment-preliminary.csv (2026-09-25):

Signal | MAX10 package pin | I/O standard | Notes
FPGA_ADC_D15 | 38 | 3.3-V LVCMOS | Must pass Quartus legality compile before release
FPGA_ADC_D14 | 39 | 3.3-V LVCMOS | Must pass Quartus legality compile before release
FPGA_ADC_D13 | 41 | 3.3-V LVCMOS | Must pass Quartus legality compile before release
FPGA_ADC_D12 | 43 | 3.3-V LVCMOS | Must pass Quartus legality compile before release
FPGA_ADC_D11 | 44 | 3.3-V LVCMOS | Must pass Quartus legality compile before release
FPGA_ADC_D10 | 45 | 3.3-V LVCMOS | Must pass Quartus legality compile before release
FPGA_ADC_D9 | 46 | 3.3-V LVCMOS | Must pass Quartus legality compile before release
FPGA_ADC_D8 | 47 | 3.3-V LVCMOS | Must pass Quartus legality compile before release
FPGA_ADC_D7 | 50 | 3.3-V LVCMOS | Must pass Quartus legality compile before release
FPGA_ADC_D6 | 52 | 3.3-V LVCMOS | Must pass Quartus legality compile before release
FPGA_ADC_D5 | 54 | 3.3-V LVCMOS | Must pass Quartus legality compile before release
FPGA_REFCLK | 56 | 3.3-V LVCMOS | Must pass Quartus legality compile before release
FPGA_ADCCLK | 58 | 3.3-V LVCMOS | Must pass Quartus legality compile before release
FPGA_ADC_D3 | 59 | 3.3-V LVCMOS | Must pass Quartus legality compile before release
FPGA_ADC_D2 | 60 | 3.3-V LVCMOS | Must pass Quartus legality compile before release
FPGA_ADC_D1 | 61 | 3.3-V LVCMOS | Must pass Quartus legality compile before release
FPGA_ADC_D0 | 62 | 3.3-V LVCMOS | Must pass Quartus legality compile before release
FPGA_ADC_D4 | 64 | 3.3-V LVCMOS | Must pass Quartus legality compile before release
ADC_OVR | 69 | 3.3-V LVCMOS | Must pass Quartus legality compile before release
HOST_D7 | 74 | 3.3-V LVCMOS | Must pass Quartus legality compile before release
HOST_D6 | 75 | 3.3-V LVCMOS | Must pass Quartus legality compile before release
HOST_D5 | 76 | 3.3-V LVCMOS | Must pass Quartus legality compile before release
HOST_D4 | 77 | 3.3-V LVCMOS | Must pass Quartus legality compile before release
HOST_D3 | 78 | 3.3-V LVCMOS | Must pass Quartus legality compile before release
HOST_D2 | 79 | 3.3-V LVCMOS | Must pass Quartus legality compile before release
HOST_D1 | 80 | 3.3-V LVCMOS | Must pass Quartus legality compile before release
HOST_D0 | 81 | 3.3-V LVCMOS | Must pass Quartus legality compile before release
HOST_WR | 84 | 3.3-V LVCMOS | Must pass Quartus legality compile before release
HOST_RD | 85 | 3.3-V LVCMOS | Must pass Quartus legality compile before release
HOST_CS | 86 | 3.3-V LVCMOS | Must pass Quartus legality compile before release
HOST_IRQ | 87 | 3.3-V LVCMOS | Must pass Quartus legality compile before release
HOST_SCK | 88 | 3.3-V LVCMOS | Must pass Quartus legality compile before release
HOST_MOSI | 89 | 3.3-V LVCMOS | Must pass Quartus legality compile before release
HOST_MISO | 90 | 3.3-V LVCMOS | Must pass Quartus legality compile before release
HOST_AUX | 91 | 3.3-V LVCMOS | Must pass Quartus legality compile before release
FPGA_RESET_N | 92 | 3.3-V LVCMOS | Must pass Quartus legality compile before release
EXT_TRIG | 93 | 3.3-V LVCMOS | Must pass Quartus legality compile before release
FPGA_RUN | 110 | 3.3-V LVCMOS | Must pass Quartus legality compile before release
FPGA_TRIG | 111 | 3.3-V LVCMOS | Must pass Quartus legality compile before release
FPGA_SAT | 120 | 3.3-V LVCMOS | Must pass Quartus legality compile before release

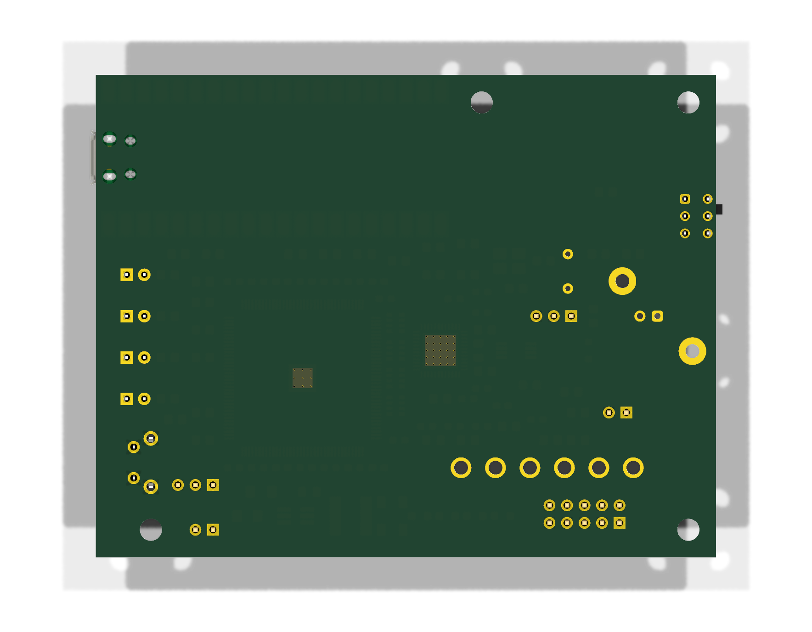
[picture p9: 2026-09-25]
hardware/rev2.0-preliminary/reference/Aster-MCA-v2.0-bottom.png

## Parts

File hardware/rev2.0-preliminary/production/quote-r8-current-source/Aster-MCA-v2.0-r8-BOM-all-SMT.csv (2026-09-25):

Comment | Designator | Footprint | LCSC Part # | Manufacturer Part Number | Qty
100n | C10,C11,C12,C13,C14,C15,C16,C17,C18,C19,C20,C21,C22,C23,C24,C30,C31,C32,C33,C34,C35,C36,C37,C42,C5,C7,C9 | Capacitor_SMD:C_0603_1608Metric | C1853266 | CC0603KPX7R8BB104 | 27
2.2n C0G | C2 | Capacitor_SMD:C_0603_1608Metric | C343869 | GCM1885C1H222JA16D | 1
4.7u | C25,C26,C27,C29 | Capacitor_SMD:C_0805_2012Metric_Pad1.18x1.45mm_HandSolder |  |  | 4
10u | C28 | Capacitor_SMD:C_0805_2012Metric_Pad1.18x1.45mm_HandSolder |  |  | 1
100n | C38 | Capacitor_SMD:C_0402_1005Metric | C1525 | CL05B104KO5NNNC | 1
10u 10V | C39 | Capacitor_SMD:C_1206_3216Metric_Pad1.33x1.80mm_HandSolder |  |  | 1
22u 6.3V | C40,C41 | Capacitor_SMD:C_1206_3216Metric_Pad1.33x1.80mm_HandSolder |  |  | 2
2.2u | C6 | Capacitor_SMD:C_0805_2012Metric_Pad1.18x1.45mm_HandSolder |  |  | 1
1u | C8 | Capacitor_SMD:C_0805_2012Metric_Pad1.18x1.45mm_HandSolder |  |  | 1
SS14L USB OR | D6 | Diode_SMD:D_SOD-123F | C190475 | SS14L | 1
SS14L EXT OR | D7 | Diode_SMD:D_SOD-123F | C190475 | SS14L | 1
1.5A RESETTABLE | F1 | Fuse:Fuse_1206_3216Metric_Pad1.42x1.75mm_HandSolder |  | 1206L150 | 1
600R@100MHz 1A | FB1,FB2,FB3,FB4 | Inductor_SMD:L_0805_2012Metric_Pad1.05x1.20mm_HandSolder |  | BLM21PG601SN1D | 4
3.9uH >=3A | L1 | Inductor_SMD:L_Changjiang_FNR6020S |  | FNR6020S-3R9M | 1
22R 1% | R10,R9 | Resistor_SMD:R_0805_2012Metric |  |  | 2
10k | R11,R14,R33,R34,R35,R37,R38,R39,R40,R41 | Resistor_SMD:R_0805_2012Metric_Pad1.20x1.40mm_HandSolder |  |  | 10
8k25 1% | R12 | Resistor_SMD:R_0805_2012Metric_Pad1.20x1.40mm_HandSolder |  |  | 1
4k99 1% | R13 | Resistor_SMD:R_0805_2012Metric_Pad1.20x1.40mm_HandSolder |  |  | 1
33R | R15,R16 | Resistor_SMD:R_0805_2012Metric_Pad1.20x1.40mm_HandSolder |  |  | 2
78R7 0.1% | R2,R4 | Aster_Production:Resistor_SMD__R_0805_2012Metric_Pad1.20x1.40mm_HandSolder__AsterProd |  |  | 2
0R | R3 | Resistor_SMD:R_0805_2012Metric_Pad1.20x1.40mm_HandSolder |  |  | 1
1k | R36,R42,R43,R44,R45 | Resistor_SMD:R_0805_2012Metric_Pad1.20x1.40mm_HandSolder |  |  | 5
324R 0.1% | R46 | Aster_Production:Resistor_SMD__R_0805_2012Metric_Pad1.20x1.40mm_HandSolder__AsterProd |  |  | 1
402R 0.1% | R47 | Aster_Production:Resistor_SMD__R_0805_2012Metric_Pad1.20x1.40mm_HandSolder__AsterProd |  |  | 1
3k92 0.1% | R5 | Aster_Production:Resistor_SMD__R_0805_2012Metric_Pad1.20x1.40mm_HandSolder__AsterProd |  |  | 1
4k00 0.1% | R6 | Resistor_SMD:R_0805_2012Metric_Pad1.20x1.40mm_HandSolder |  |  | 1
2k00 0.1% | R7,R8 | Resistor_SMD:R_0805_2012Metric_Pad1.20x1.40mm_HandSolder |  |  | 2
33R x4 isolated | RN1,RN2,RN3,RN4 | Resistor_SMD:R_Array_Convex_4x0603 | C102663 | RTA03-4D330JTP | 4
10M16SAE144C8G | U1 | Package_QFP:EQFP-144-1EP_20x20mm_P0.5mm_EP4x4mm | C1521931 | 10M16SAE144C8G | 1
ADS5560IRGZT | U2 | Package_DFN_QFN:Texas_RGZ0048A_VQFN-48-1EP_7x7mm_P0.5mm_EP5.15x5.15mm | C571255 | ADS5560IRGZT | 1
THS4551IDGKT | U3 | Package_SO:VSSOP-8_3x3mm_P0.65mm | C2860660 | THS4551IDGKT | 1
AP63203WU-7 | U4 | Package_TO_SOT_SMD:TSOT-23-6_HandSoldering | C780769 | AP63203WU-7 | 1
40.000 MHz CMOS | Y1 | Oscillator:Oscillator_SMD_Abracon_ASE-4Pin_3.2x2.5mm_HandSoldering | C1670009 | ASE-40.000MHZ-L-C-T | 1

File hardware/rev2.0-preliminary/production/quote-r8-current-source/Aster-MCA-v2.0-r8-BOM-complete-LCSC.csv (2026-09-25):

Comment | Designator | Footprint | LCSC Part # | Manufacturer Part Number | Qty | Assembly | Purchase Notes
RP2350 Pico 2 compatible 52x21mm | A1 | Aster_Custom:RP2350_Clone_52x21mm_Castellated |  | RP2350 Pico 2 compatible | 1 | MODULE/HAND | User-supplied module; castellated soldering; no confirmed LCSC part
2.2nF C0G 50V | C2 | Capacitor_SMD:C_0603_1608Metric | C343869 | GCM1885C1H222JA16D | 1 | SMT
100nF X7R 25V | C5,C7,C9,C10,C11,C12,C13,C14,C15,C16,C17,C18,C19,C20,C21,C22,C23,C24,C30,C31,C32,C33,C34,C35,C36,C37,C42 | Capacitor_SMD:C_0603_1608Metric | C1853266 | CC0603KPX7R8BB104 | 27 | SMT
2.2uF X7R 16V | C6 | Capacitor_SMD:C_0805_2012Metric_Pad1.18x1.45mm_HandSolder | C28234 | CL21B225KOFNNNE | 1 | SMT
1uF X7R 16V | C8 | Capacitor_SMD:C_0805_2012Metric_Pad1.18x1.45mm_HandSolder | C24123 | CL21B105KOFNNNE | 1 | SMT
4.7uF X5R 16V | C25,C26,C27,C29 | Capacitor_SMD:C_0805_2012Metric_Pad1.18x1.45mm_HandSolder | C1746 | CL21A475KOFNNNE | 4 | SMT
10uF X5R 16V | C28 | Capacitor_SMD:C_0805_2012Metric_Pad1.18x1.45mm_HandSolder | C77075 | GRM21BR61C106KE15L | 1 | SMT
100nF X7R 16V | C38 | Capacitor_SMD:C_0402_1005Metric | C1525 | CL05B104KO5NNNC | 1 | SMT
10uF X7R 10V | C39 | Capacitor_SMD:C_1206_3216Metric_Pad1.33x1.80mm_HandSolder | C165101 | 1206B106K100NT | 1 | SMT
22uF X5R 6.3V | C40,C41 | Capacitor_SMD:C_1206_3216Metric_Pad1.33x1.80mm_HandSolder | C159759 | CL31A226KQHNNNE | 2 | SMT
PWR green LED 3mm | D2 | LED_THT:LED_D3.0mm | C3028822 | MHL3014UGDGT | 1 | HAND | Long lead is anode
RUN green LED 3mm | D3 | LED_THT:LED_D3.0mm | C3028822 | MHL3014UGDGT | 1 | HAND | Long lead is anode
TRIG yellow LED 3mm | D4 | LED_THT:LED_D3.0mm | C6402159 | 264-10UYD/S530-A3 | 1 | HAND | Long lead is anode
SAT red LED 3mm | D5 | LED_THT:LED_D3.0mm | C84774 | 204-10SDRD/S530-A3-L | 1 | HAND | Long lead is anode
SS14L Schottky | D6,D7 | Diode_SMD:D_SOD-123F | C190475 | SS14L | 2 | SMT | Observe cathode stripe
1.5A resettable fuse 24V | F1 | Fuse:Fuse_1206_3216Metric_Pad1.42x1.75mm_HandSolder | C20627120 | 1206L150/24NR | 1 | SMT
600ohm@100MHz 1A ferrite bead | FB1,FB2,FB3,FB4 | Inductor_SMD:L_0805_2012Metric_Pad1.05x1.20mm_HandSolder | C41556732 | BLM21PG601SN1D | 4 | SMT
BNC input vertical | J1 | Connector_Coaxial:BNC_Amphenol_031-5539_Vertical | C6634490 | 031-5539 | 1 | HAND | Exact footprint part; may require external purchase if unavailable
Intel JTAG 2x5 2.54mm | J2 | Connector_PinHeader_2.54mm:PinHeader_2x05_P2.54mm_Vertical | C32713278 | HX PZ2.54-2x5P ZZ | 1 | HAND
1x3 2.54mm pin header | J3,JP2 | Connector_PinHeader_2.54mm:PinHeader_1x03_P2.54mm_Vertical | C32713269 | HX PZ2.54-1x3P ZZ | 2 | HAND
1x2 2.54mm pin header | J4,JP1 | Connector_PinHeader_2.54mm:PinHeader_1x02_P2.54mm_Vertical | C32713268 | HX PZ2.54-1x2P ZZ | 2 | HAND
3.9uH power inductor | L1 | Inductor_SMD:L_Changjiang_FNR6020S | C168006 | FNR6020S3R9NT | 1 | SMT | Exact footprint part; current LCSC stock may be zero
10k 1% 0805 | R11,R14,R33,R34,R35,R37,R38,R39,R40,R41 | Resistor_SMD:R_0805_2012Metric_Pad1.20x1.40mm_HandSolder | C17414 | 0805W8F1002T5E | 10 | SMT
8.25k 1% 0805 | R12 | Resistor_SMD:R_0805_2012Metric_Pad1.20x1.40mm_HandSolder | C3000539 | FRC0805F8251TS | 1 | SMT
4.99k 1% 0805 | R13 | Resistor_SMD:R_0805_2012Metric_Pad1.20x1.40mm_HandSolder | C17677 | 0805W8F4991T5E | 1 | SMT
33ohm 1% 0805 | R15,R16 | Resistor_SMD:R_0805_2012Metric_Pad1.20x1.40mm_HandSolder | C17634 | 0805W8F330JT5E | 2 | SMT
78.7ohm 0.1% 0805 | R2,R4 | Aster_Production:Resistor_SMD__R_0805_2012Metric_Pad1.20x1.40mm_HandSolder__AsterProd | C2849344 | PTFR0805B78R7P9 | 2 | SMT
0ohm jumper 0805 | R3 | Resistor_SMD:R_0805_2012Metric_Pad1.20x1.40mm_HandSolder | C17477 | 0805W8F0000T5E | 1 | SMT
1k 1% 0805 | R36,R42,R43,R44,R45 | Resistor_SMD:R_0805_2012Metric_Pad1.20x1.40mm_HandSolder | C17513 | 0805W8F1001T5E | 5 | SMT
3.92k 0.1% 0805 | R5 | Aster_Production:Resistor_SMD__R_0805_2012Metric_Pad1.20x1.40mm_HandSolder__AsterProd | C865470 | RT0805BRD073K92L | 1 | SMT
4.00k 0.1% 0805 | R6 | Resistor_SMD:R_0805_2012Metric_Pad1.20x1.40mm_HandSolder | C1700252 | MCU08050D4001BP500 | 1 | SMT | Exact value; current LCSC stock may be zero
2.00k 0.1% 0805 | R7,R8 | Resistor_SMD:R_0805_2012Metric_Pad1.20x1.40mm_HandSolder | C706274 | RT0805BRE072KL | 2 | SMT
22ohm 1% 0805 | R9,R10 | Resistor_SMD:R_0805_2012Metric | C17561 | 0805W8F220JT5E | 2 | SMT | r8 ADC-driver damping value
324ohm 0.1% 0805 | R46 | Aster_Production:Resistor_SMD__R_0805_2012Metric_Pad1.20x1.40mm_HandSolder__AsterProd | C2984390 | AR05BTCW3240 | 1 | SMT
402ohm 0.1% 0805 | R47 | Aster_Production:Resistor_SMD__R_0805_2012Metric_Pad1.20x1.40mm_HandSolder__AsterProd | C865474 | RT0805BRD07402RL | 1 | SMT
33ohm x4 isolated resistor array | RN1,RN2,RN3,RN4 | Resistor_SMD:R_Array_Convex_4x0603 | C102663 | RTA03-4D330JTP | 4 | SMT | Four isolated resistors per package
Gain switch DP3T right-angle | SW1 | Aster_Production:Button_Switch_THT__SW_CK_JS203011AQN_DP3T_Angled__AsterProd | C221667 | JS203011AQN | 1 | HAND | Verify physical slider order by continuity before assembly
FPGA reconfigure pushbutton | SW2 | Button_Switch_THT:SW_Tactile_SPST_Angled_PTS645Vx39-2LFS | C285523 | PTS645VL39-2 LFS | 1 | HAND | Exact footprint part; may require external purchase if unavailable
Intel MAX 10 FPGA | U1 | Package_QFP:EQFP-144-1EP_20x20mm_P0.5mm_EP4x4mm | C1521931 | 10M16SAE144C8G | 1 | SMT | Exact part; currently expensive and stock-dependent
16-bit 40MSPS ADC | U2 | Package_DFN_QFN:Texas_RGZ0048A_VQFN-48-1EP_7x7mm_P0.5mm_EP5.15x5.15mm | C571255 | ADS5560IRGZT | 1 | SMT | Exact part; currently expensive and stock-dependent
Fully differential ADC driver | U3 | Package_SO:VSSOP-8_3x3mm_P0.65mm | C2860660 | THS4551IDGKT | 1 | SMT
3.3V buck regulator | U4 | Package_TO_SOT_SMD:TSOT-23-6_HandSoldering | C780769 | AP63203WU-7 | 1 | SMT
40.000MHz CMOS oscillator | Y1 | Oscillator:Oscillator_SMD_Abracon_ASE-4Pin_3.2x2.5mm_HandSoldering | C1670009 | ASE-40.000MHZ-L-C-T | 1 | SMT | Exact oscillator; stock may be limited

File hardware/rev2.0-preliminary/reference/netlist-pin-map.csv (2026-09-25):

Reference | Pin | Net
A1
A1
A1
A1
A1 | 1 | HOST_D0
A1 | 2 | HOST_D1
A1 | 3 | GND
A1 | 4 | HOST_D2
A1 | 5 | HOST_D3
A1 | 6 | HOST_D4
A1 | 7 | HOST_D5
A1 | 8 | GND
A1 | 9 | HOST_D6
A1 | 10 | HOST_D7
A1 | 11 | HOST_WR
A1 | 12 | HOST_RD
A1 | 13 | GND
A1 | 14 | HOST_CS
A1 | 15 | HOST_IRQ
A1 | 16 | HOST_SCK
A1 | 17 | HOST_MOSI
A1 | 18 | GND
A1 | 19 | HOST_MISO
A1 | 20 | HOST_AUX
A1 | 21 | FPGA_RESET_N
A1 | 22 | EXT_TRIG
A1 | 23 | GND
A1 | 24
A1 | 25
A1 | 26
A1 | 27
A1 | 28 | GND
A1 | 29
A1 | 30
A1 | 31
A1 | 32
A1 | 33 | GND
A1 | 34
A1 | 35
A1 | 36
A1 | 37
A1 | 38 | GND
A1 | 39
A1 | 40 | VBUS
C1 | 1 | AFE_IN
C1 | 2 | AFE_AC
C2 | 1 | ADC_INP
C2 | 2 | ADC_INM
C5 | 1 | 5VA
C5 | 2 | GND
C6 | 1 | 5VA
C6 | 2 | GND
C7 | 1 | ADC_VCM
C7 | 2 | GND
C8 | 1 | ADC_VCM
C8 | 2 | GND
C9 | 1 | ADC_CLKM
C9 | 2 | GND
C10 | 1 | CLK40_RAW
C10 | 2 | ADC_CLKP
C11 | 1 | 3V3_D
C11 | 2 | GND
C12 | 1 | 3V3_D
C12 | 2 | GND
C13 | 1 | 3V3_D
C13 | 2 | GND
C14 | 1 | 3V3_D
C14 | 2 | GND
C15 | 1 | 3V3_D
C15 | 2 | GND
C16 | 1 | 3V3_D
C16 | 2 | GND
C17 | 1 | 3V3_D
C17 | 2 | GND
C18 | 1 | 3V3_D
C18 | 2 | GND
C19 | 1 | 3V3_D
C19 | 2 | GND
C20 | 1 | 3V3_D
C20 | 2 | GND
C21 | 1 | 3V3_FPGA_A
C21 | 2 | GND
C22 | 1 | 3V3_FPGA_A
C22 | 2 | GND
C23 | 1 | 3V3_FPGA_A
C23 | 2 | GND
C24 | 1 | 3V3_FPGA_A
C24 | 2 | GND
C25 | 1 | 3V3_D
C25 | 2 | GND
C26 | 1 | 3V3_FPGA_A
C26 | 2 | GND
C27 | 1 | 3V3_D
C27 | 2 | GND
C28 | 1 | 3V3_A
C28 | 2 | GND
C29 | 1 | 3V3_D
C29 | 2 | GND
C30 | 1 | 3V3_A
C30 | 2 | GND
C31 | 1 | 3V3_D
C31 | 2 | GND
C32 | 1 | 3V3_A
C32 | 2 | GND
C33 | 1 | 3V3_A
C33 | 2 | GND
C34 | 1 | 3V3_A
C34 | 2 | GND
C35 | 1 | 3V3_A
C35 | 2 | GND
C36 | 1 | 3V3_D
C36 | 2 | GND
C37 | 1 | 3V3_D
C37 | 2 | GND
C38 | 1 | BUCK_BST
C38 | 2 | BUCK_SW
C39 | 1 | 5V_FUSED
C39 | 2 | GND
C40 | 1 | 3V3_RAW
C40 | 2 | GND
C41 | 1 | 3V3_RAW
C41 | 2 | GND
C42 | 1 | 3V3_D
C42 | 2 | GND
D1 | 1 | GND
D1 | 2 | AFE_IN
D2 | 1 | LED_R1
D2 | 2 | 3V3_D
D3 | 1 | LED_R2
D3 | 2 | FPGA_RUN
D4 | 1 | LED_R3
D4 | 2 | FPGA_TRIG
D5 | 1 | LED_R4
D5 | 2 | FPGA_SAT
D6 | 1 | 5V_FUSED
D6 | 2 | USB_5V_PROTECTED
D7 | 1 | 5V_FUSED
D7 | 2 | ALT_5V_IN
F1 | 1 | VBUS
F1 | 2 | USB_5V_PROTECTED
FB1 | 1 | 3V3_RAW
FB1 | 2 | 3V3_D
FB2 | 1 | 3V3_RAW
FB2 | 2 | 3V3_A
FB3 | 1 | 3V3_RAW
FB3 | 2 | 3V3_FPGA_A
FB4 | 1 | 5V_FUSED
FB4 | 2 | 5VA
H1
H2
H3
H4
J1
J1
J1 | 1 | PMT_IN
J1 | 2 | GND
J2 | 1 | JTAG_TCK
J2 | 2 | GND
J2 | 3 | JTAG_TDO
J2 | 4 | 3V3_D
J2 | 5 | JTAG_TMS
J2 | 6
J2 | 7
J2 | 8
J2 | 9 | JTAG_TDI
J2 | 10 | GND
J3 | 1 | 3V3_D
J3 | 2 | EXT_TRIG
J3 | 3 | GND
J4 | 1 | ALT_5V_IN
J4 | 2 | GND
JP1 | 1 | PMT_IN
JP1 | 2 | TERM_50
JP2 | 1 | AFE_IN
JP2 | 2 | GAIN_SRC
JP2 | 3 | AFE_AC
L1 | 1 | BUCK_SW
L1 | 2 | 3V3_RAW
R1 | 1 | TERM_50
R1 | 2 | GND
R2 | 1 | PMT_IN
R2 | 2 | AFE_IN
R3 | 1 | GAIN_H_SIG
R3 | 2 | FDA_INN
R4 | 1 | GAIN_H_GND
R4 | 2 | FDA_INP
R5 | 1 | GAIN_L_SIG
R5 | 2 | FDA_INN
R6 | 1 | GAIN_L_GND
R6 | 2 | FDA_INP
R7 | 1 | FDA_OUTP
R7 | 2 | FDA_INN
R8 | 1 | FDA_OUTN
R8 | 2 | FDA_INP
R9 | 1 | FDA_OUTP
R9 | 2 | ADC_INM
R10 | 1 | FDA_OUTN
R10 | 2 | ADC_INP
R11 | 1 | 5VA
R11 | 2 | FDA_PD
R12 | 1 | 3V3_D
R12 | 2 | ADC_DFS
R13 | 1 | ADC_DFS
R13 | 2 | GND
R14 | 1 | 3V3_D
R14 | 2 | CLK_OE
R15 | 1 | CLK40_RAW
R15 | 2 | FPGA_REFCLK
R16 | 1 | ADC_CLKOUT
R16 | 2 | FPGA_ADCCLK
R33 | 1 | 3V3_D
R33 | 2 | JTAGEN
R34 | 1 | 3V3_D
R34 | 2 | JTAG_TMS
R35 | 1 | 3V3_D
R35 | 2 | JTAG_TDI
R36 | 1 | JTAG_TCK
R36 | 2 | GND
R37 | 1 | 3V3_D
R37 | 2 | NCONFIG
R38 | 1 | 3V3_D
R38 | 2 | NSTATUS
R39 | 1 | 3V3_D
R39 | 2 | CONF_DONE
R40 | 1 | 3V3_D
R40 | 2 | FPGA_RESET_N
R41 | 1 | 3V3_D
R41 | 2 | EXT_TRIG
R42 | 1 | GND
R42 | 2 | LED_R1
R43 | 1 | GND
R43 | 2 | LED_R2
R44 | 1 | GND
R44 | 2 | LED_R3
R45 | 1 | GND
R45 | 2 | LED_R4
R46 | 1 | GAIN_M_SIG
R46 | 2 | FDA_INN
R47 | 1 | GAIN_M_GND
R47 | 2 | FDA_INP
RN1 | 1 | ADC_D15
RN1 | 2 | ADC_D14
RN1 | 3 | ADC_D13
RN1 | 4 | ADC_D12
RN1 | 5 | FPGA_ADC_D12
RN1 | 6 | FPGA_ADC_D13
RN1 | 7 | FPGA_ADC_D14
RN1 | 8 | FPGA_ADC_D15
RN2 | 1 | ADC_D11
RN2 | 2 | ADC_D10
RN2 | 3 | ADC_D9
RN2 | 4 | ADC_D8
RN2 | 5 | FPGA_ADC_D8
RN2 | 6 | FPGA_ADC_D9
RN2 | 7 | FPGA_ADC_D10
RN2 | 8 | FPGA_ADC_D11
RN3 | 1 | ADC_D7
RN3 | 2 | ADC_D6
RN3 | 3 | ADC_D5
RN3 | 4 | ADC_D4
RN3 | 5 | FPGA_ADC_D4
RN3 | 6 | FPGA_ADC_D5
RN3 | 7 | FPGA_ADC_D6
RN3 | 8 | FPGA_ADC_D7
RN4 | 1 | ADC_D3
RN4 | 2 | ADC_D2
RN4 | 3 | ADC_D1
RN4 | 4 | ADC_D0
RN4 | 5 | FPGA_ADC_D0
RN4 | 6 | FPGA_ADC_D1
RN4 | 7 | FPGA_ADC_D2
RN4 | 8 | FPGA_ADC_D3
SW1 | 1 | GAIN_H_SIG
SW1 | 2 | GAIN_M_SIG
SW1 | 3 | GAIN_SRC
SW1 | 4 | GAIN_L_SIG
SW1 | 5 | GAIN_H_GND
SW1 | 6 | GAIN_M_GND
SW1 | 7 | GND
SW1 | 8 | GAIN_L_GND
SW2
SW2
SW2 | 1 | NCONFIG
SW2 | 2 | GND
TP1 | 1 | GND
TP2 | 1 | 5V_FUSED
TP3 | 1 | 3V3_D
TP4 | 1 | 3V3_A
TP5 | 1 | ADC_VCM
U1
U1
U1
U1
U1
U1
U1
U1
U1
U1 | 1 | 3V3_FPGA_A
U1 | 2 | 3V3_FPGA_A
U1 | 3 | GND
U1 | 4 | GND
U1 | 5
U1 | 6
U1 | 7
U1 | 8
U1 | 9 | 3V3_D
U1 | 10
U1 | 11
U1 | 12
U1 | 13
U1 | 14
U1 | 15 | JTAGEN
U1 | 16 | JTAG_TMS
U1 | 17
U1 | 18 | JTAG_TCK
U1 | 19 | JTAG_TDI
U1 | 20 | JTAG_TDO
U1 | 21
U1 | 22
U1 | 23 | 3V3_D
U1 | 24
U1 | 25
U1 | 26
U1 | 27
U1 | 28
U1 | 29
U1 | 30
U1 | 31 | 3V3_D
U1 | 32
U1 | 33
U1 | 34 | 3V3_FPGA_A
U1 | 35 | 3V3_FPGA_A
U1 | 36 | 3V3_FPGA_A
U1 | 37 | 3V3_FPGA_A
U1 | 38 | FPGA_ADC_D15
U1 | 39 | FPGA_ADC_D14
U1 | 40 | 3V3_D
U1 | 41 | FPGA_ADC_D13
U1 | 42 | GND
U1 | 43 | FPGA_ADC_D12
U1 | 44 | FPGA_ADC_D11
U1 | 45 | FPGA_ADC_D10
U1 | 46 | FPGA_ADC_D9
U1 | 47 | FPGA_ADC_D8
U1 | 48
U1 | 49 | 3V3_D
U1 | 50 | FPGA_ADC_D7
U1 | 51 | 3V3_FPGA_A
U1 | 52 | FPGA_ADC_D6
U1 | 53 | GND
U1 | 54 | FPGA_ADC_D5
U1 | 55
U1 | 56 | FPGA_REFCLK
U1 | 57
U1 | 58 | FPGA_ADCCLK
U1 | 59 | FPGA_ADC_D3
U1 | 60 | FPGA_ADC_D2
U1 | 61 | FPGA_ADC_D1
U1 | 62 | FPGA_ADC_D0
U1 | 63 | GND
U1 | 64 | FPGA_ADC_D4
U1 | 65
U1 | 66
U1 | 67 | 3V3_D
U1 | 68 | GND
U1 | 69 | ADC_OVR
U1 | 70
U1 | 71 | 3V3_FPGA_A
U1 | 72 | 3V3_FPGA_A
U1 | 73 | 3V3_FPGA_A
U1 | 74 | HOST_D7
U1 | 75 | HOST_D6
U1 | 76 | HOST_D5
U1 | 77 | HOST_D4
U1 | 78 | HOST_D3
U1 | 79 | HOST_D2
U1 | 80 | HOST_D1
U1 | 81 | HOST_D0
U1 | 82 | 3V3_D
U1 | 83 | GND
U1 | 84 | HOST_WR
U1 | 85 | HOST_RD
U1 | 86 | HOST_CS
U1 | 87 | HOST_IRQ
U1 | 88 | HOST_SCK
U1 | 89 | HOST_MOSI
U1 | 90 | HOST_MISO
U1 | 91 | HOST_AUX
U1 | 92 | FPGA_RESET_N
U1 | 93 | EXT_TRIG
U1 | 94 | 3V3_D
U1 | 95 | GND
U1 | 96
U1 | 97
U1 | 98
U1 | 99
U1 | 100
U1 | 101
U1 | 102
U1 | 103 | 3V3_D
U1 | 104 | GND
U1 | 105
U1 | 106
U1 | 107 | 3V3_FPGA_A
U1 | 108 | 3V3_FPGA_A
U1 | 109 | 3V3_FPGA_A
U1 | 110 | FPGA_RUN
U1 | 111 | FPGA_TRIG
U1 | 112
U1 | 113
U1 | 114
U1 | 115 | 3V3_FPGA_A
U1 | 116 | GND
U1 | 117 | 3V3_D
U1 | 118
U1 | 119
U1 | 120 | FPGA_SAT
U1 | 121
U1 | 122
U1 | 123
U1 | 124
U1 | 125 | GND
U1 | 126
U1 | 127
U1 | 128 | 3V3_D
U1 | 129 | NCONFIG
U1 | 130
U1 | 131
U1 | 132
U1 | 133 | GND
U1 | 134
U1 | 135
U1 | 136 | NSTATUS
U1 | 137 | GND
U1 | 138 | CONF_DONE
U1 | 139 | 3V3_D
U1 | 140
U1 | 141
U1 | 142 | GND
U1 | 143 | 3V3_FPGA_A
U1 | 144 | 3V3_FPGA_A
U1 | 145 | GND
U2
U2
U2
U2
U2
U2
U2
U2
U2
U2
U2
U2
U2
U2
U2
U2
U2 | 1 | GND
U2 | 2 | 3V3_D
U2 | 3 | ADC_OVR
U2 | 4
U2 | 5 | ADC_CLKOUT
U2 | 6 | ADC_DFS
U2 | 7 | 3V3_D
U2 | 8 | 3V3_A
U2 | 9 | GND
U2 | 10 | ADC_CLKP
U2 | 11 | ADC_CLKM
U2 | 12 | GND
U2 | 13 | ADC_VCM
U2 | 14 | GND
U2 | 15 | ADC_INP
U2 | 16 | ADC_INM
U2 | 17 | GND
U2 | 18 | 3V3_A
U2 | 19 | GND
U2 | 20 | 3V3_A
U2 | 21
U2 | 22 | 3V3_A
U2 | 23 | GND
U2 | 24 | 3V3_A
U2 | 25 | GND
U2 | 26 | 3V3_A
U2 | 27 | 3V3_D
U2 | 28 | GND
U2 | 29 | GND
U2 | 30 | 3V3_D
U2 | 31 | ADC_D0
U2 | 32 | ADC_D1
U2 | 33 | ADC_D2
U2 | 34 | ADC_D3
U2 | 35 | 3V3_D
U2 | 36 | GND
U2 | 37 | ADC_D4
U2 | 38 | ADC_D5
U2 | 39 | ADC_D6
U2 | 40 | ADC_D7
U2 | 41 | ADC_D8
U2 | 42 | ADC_D9
U2 | 43 | ADC_D10
U2 | 44 | ADC_D11
U2 | 45 | ADC_D12
U2 | 46 | ADC_D13
U2 | 47 | ADC_D14
U2 | 48 | ADC_D15
U2 | 49 | GND
U3 | 1 | FDA_INN
U3 | 2 | ADC_VCM
U3 | 3 | 5VA
U3 | 4 | FDA_OUTP
U3 | 5 | FDA_OUTN
U3 | 6 | GND
U3 | 7 | FDA_PD
U3 | 8 | FDA_INP
U4 | 1 | 3V3_RAW
U4 | 2 | 5V_FUSED
U4 | 3 | 5V_FUSED
U4 | 4 | GND
U4 | 5 | BUCK_SW
U4 | 6 | BUCK_BST
Y1 | 1 | CLK_OE
Y1 | 2 | GND
Y1 | 3 | CLK40_RAW
Y1 | 4 | 3V3_D

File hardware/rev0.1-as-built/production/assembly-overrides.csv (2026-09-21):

Designator | Required action | Reason
U8 | Fit MCP6001T-I/OT instead of LMV321IDBVR | PCB net map requires 1 OUT 2 VSS 3 IN+ 4 IN- 5 VDD
S1 | DNP | Selected tactile switch contact pairing can hold RECONFIG_N low
U6 | Fit the original SGM2037-1.2XN5G/TR for new builds | AP2112K-1.2 was tested to start without extra capacitance; add parallel output capacitance only if measurements prove an overly fast +1V2 rise causes FPGA startup failure and then verify stability and overshoot
J2 | Hand fit a grounded low-voltage BNC | Not included in SMT placement
R60 | DNP unless input termination has been evaluated | Termination depends on the connected front end
R66;R67 | DNP for gain 10 or fit the same matched value at both positions | Each pad is parallel to its corresponding fitted 10k feedback resistor; validation used 4.99k 0.1% on both positions for gain about 3.33

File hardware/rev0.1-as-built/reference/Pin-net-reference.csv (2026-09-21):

Designator | Pin | Net
C1 | 1 | USB5V
C1 | 2 | GND
C2 | 1 | USB5V
C2 | 2 | GND
C3 | 1 | +3V3
C3 | 2 | GND
C4 | 1 | +3V3
C4 | 2 | GND
C5 | 1 | +3V3
C5 | 2 | GND
C6 | 1 | +1V2
C6 | 2 | GND
C7 | 1 | +3V3
C7 | 2 | GND
C8 | 1 | +3V3
C8 | 2 | GND
C9 | 1 | CH347_RST_N
C9 | 2 | GND
C10 | 1 | CH347_XI
C10 | 2 | GND
C11 | 1 | CH347_XO
C11 | 2 | GND
C12 | 1 | +5VA
C12 | 2 | GND
C13 | 1 | +5VA
C13 | 2 | GND
C20 | 1 | +1V2
C20 | 2 | GND
C21 | 1 | +1V2
C21 | 2 | GND
C22 | 1 | +1V2
C22 | 2 | GND
C23 | 1 | +1V2
C23 | 2 | GND
C24 | 1 | +3V3
C24 | 2 | GND
C25 | 1 | +3V3
C25 | 2 | GND
C26 | 1 | +3V3
C26 | 2 | GND
C27 | 1 | +3V3
C27 | 2 | GND
C28 | 1 | +3V3
C28 | 2 | GND
C29 | 1 | +3V3
C29 | 2 | GND
C30 | 1 | +1V2
C30 | 2 | GND
C31 | 1 | +3V3
C31 | 2 | GND
C32 | 1 | RECONFIG_N
C32 | 2 | GND
C40 | 1 | +3V3
C40 | 2 | GND
C41 | 1 | +5VA
C41 | 2 | GND
C42 | 1 | ADC_VREF
C42 | 2 | GND
C43 | 1 | +5VA
C43 | 2 | GND
C44 | 1 | +5VA
C44 | 2 | GND
C45 | 1 | +5VA
C45 | 2 | GND
C46 | 1 | +5VA
C46 | 2 | GND
C47 | 1 | +5VA
C47 | 2 | GND
C48 | 1 | +5VA
C48 | 2 | GND
C49 | 1 | +3V3
C49 | 2 | GND
C50 | 1 | +3V3
C50 | 2 | GND
C51 | 1 | ADC_VREF
C51 | 2 | GND
C52 | 1 | ADC_VRN
C52 | 2 | GND
C53 | 1 | ADC_VRP
C53 | 2 | GND
C54 | 1 | ADC_VRM
C54 | 2 | GND
C60 | 1 | PULSE_IN
C60 | 2 | PULSE_AC
C61 | 1 | +5VA
C61 | 2 | GND
C62 | 1 | +5VA
C62 | 2 | GND
C63 | 1 | ADC_INP
C63 | 2 | ADC_INN
D1 | 1 | USB_DP_CONN
D1 | 2 | GND
D1 | 3 | USB_DM_CONN
D1 | 4 | USB_DM
D1 | 5 | USB5V
D1 | 6 | USB_DP
D2 | 1 | GND
D2 | 2 | PWR_LED_A
D3 | 1 | STATUS_LED_A
D3 | 2 | GND
F1 | 1 | USB_VBUS_RAW
F1 | 2 | USB5V
FB1 | 1 | USB5V
FB1 | 2 | +5VA
J1 | 1 | GND
J1 | 2 | GND
J1 | 3 | GND
J1 | 4 | GND
J1 | B8
J1 | A5 | USB_CC1
J1 | B7 | USB_DM_CONN
J1 | A6 | USB_DP_CONN
J1 | A7 | USB_DM_CONN
J1 | B6 | USB_DP_CONN
J1 | A8
J1 | B5 | USB_CC2
J1 | A1B12 | GND
J1 | B1A12 | GND
J1 | B4A9 | USB_VBUS_RAW
J1 | A4B9 | USB_VBUS_RAW
J2 | 1 | PULSE_IN
J2 | 2 | GND
J2 | 3 | GND
J2 | 4 | GND
J2 | 5 | GND
J3 | 1 | +3V3
J3 | 2 | GND
J3 | 3 | JTAG_TMS
J3 | 4 | GND
J3 | 5 | JTAG_TCK
J3 | 6 | GND
J3 | 7 | JTAG_TDI
J3 | 8 | GND
J3 | 9 | JTAG_TDO
J3 | 10 | RECONFIG_N
J4 | 1 | +3V3
J4 | 2 | GND
J4 | 3 | TRIG_OUT
J4 | 4 | FPGA_DONE
J4 | 5 | USER_IN
R1 | 1 | USB_CC1
R1 | 2 | GND
R2 | 1 | USB_CC2
R2 | 2 | GND
R3 | 1 | +3V3
R3 | 2 | CH347_RST_N
R4 | 1 | CH347_CFG0
R4 | 2 | GND
R5 | 1 | CH347_CFG1
R5 | 2 | GND
R7 | 1 | +3V3
R7 | 2 | PWR_LED_A
R8 | 1 | CH_JTAG_TMS
R8 | 2 | JTAG_TMS
R9 | 1 | CH_JTAG_TCK
R9 | 2 | JTAG_TCK
R10 | 1 | CH_JTAG_TDO
R10 | 2 | JTAG_TDO
R11 | 1 | CH_JTAG_TDI
R11 | 2 | JTAG_TDI
R20 | 1 | FPGA_MODE0
R20 | 2 | GND
R21 | 1 | FPGA_MODE1
R21 | 2 | GND
R22 | 1 | JTAGSEL_N
R22 | 2 | GND
R23 | 1 | +3V3
R23 | 2 | RECONFIG_N
R24 | 1 | +3V3
R24 | 2 | FPGA_DONE
R40 | 1 | +3V3
R40 | 2 | OSC_OE
R41 | 1 | OSC_OUT
R41 | 2 | ADC_CLK
R42 | 1 | OSC_OUT
R42 | 2 | FPGA_CLK
R43 | 1 | ADC_PD
R43 | 2 | GND
R44 | 1 | ADC_RAW_D0
R44 | 2 | ADC_D0
R45 | 1 | ADC_RAW_D1
R45 | 2 | ADC_D1
R46 | 1 | ADC_RAW_D2
R46 | 2 | ADC_D2
R47 | 1 | ADC_RAW_D3
R47 | 2 | ADC_D3
R48 | 1 | ADC_RAW_D4
R48 | 2 | ADC_D4
R49 | 1 | ADC_RAW_D5
R49 | 2 | ADC_D5
R50 | 1 | ADC_RAW_D6
R50 | 2 | ADC_D6
R51 | 1 | ADC_RAW_D7
R51 | 2 | ADC_D7
R52 | 1 | ADC_RAW_D8
R52 | 2 | ADC_D8
R53 | 1 | ADC_RAW_D9
R53 | 2 | ADC_D9
R54 | 1 | ADC_RAW_D10
R54 | 2 | ADC_D10
R55 | 1 | ADC_RAW_D11
R55 | 2 | ADC_D11
R60 | 1 | PULSE_IN
R60 | 2 | GND
R61 | 1 | PULSE_AC
R61 | 2 | VCM_BUF
R62 | 1 | PULSE_AC
R62 | 2 | AD_INP_NODE
R63 | 1 | VCM_BUF
R63 | 2 | AD_INN_NODE
R64 | 1 | OUT_N_RAW
R64 | 2 | AD_INP_NODE
R65 | 1 | OUT_P_RAW
R65 | 2 | AD_INN_NODE
R66 | 1 | OUT_N_RAW
R66 | 2 | AD_INP_NODE
R67 | 1 | OUT_P_RAW
R67 | 2 | AD_INN_NODE
R68 | 1 | +5VA
R68 | 2 | AD8137_PD
R69 | 1 | OUT_P_RAW
R69 | 2 | ADC_INN
R70 | 1 | OUT_N_RAW
R70 | 2 | ADC_INP
R80 | 1 | +3V3
R80 | 2 | USER_IN
R81 | 1 | STATUS_LED
R81 | 2 | STATUS_LED_A
S1 | 1 | RECONFIG_N
S1 | 2 | GND
S1 | 3 | RECONFIG_N
S1 | 4 | GND
U1 | 1 | +1V2
U1 | 2 | GND
U1 | 3
U1 | 4 | JTAGSEL_N
U1 | 5 | JTAG_TMS
U1 | 6 | JTAG_TCK
U1 | 7 | JTAG_TDI
U1 | 8 | JTAG_TDO
U1 | 9 | RECONFIG_N
U1 | 10 | FPGA_DONE
U1 | 11 | FPGA_CLK
U1 | 12 | +3V3
U1 | 13
U1 | 14
U1 | 15
U1 | 16
U1 | 17
U1 | 18
U1 | 19
U1 | 20
U1 | 21 | GND
U1 | 22 | +1V2
U1 | 23 | +3V3
U1 | 24 | GND
U1 | 25 | ADC_D0
U1 | 26 | ADC_D1
U1 | 27 | ADC_D2
U1 | 28 | ADC_D3
U1 | 29 | ADC_D4
U1 | 30 | ADC_D5
U1 | 31 | ADC_D6
U1 | 32 | ADC_D7
U1 | 33 | ADC_D8
U1 | 34 | ADC_D9
U1 | 35
U1 | 36
U1 | 37 | ADC_D10
U1 | 38 | ADC_D11
U1 | 39
U1 | 40
U1 | 41
U1 | 42
U1 | 43 | GND
U1 | 44 | +3V3
U1 | 45 | +1V2
U1 | 46 | GND
U1 | 47
U1 | 48
U1 | 49
U1 | 50
U1 | 51
U1 | 52
U1 | 53
U1 | 54
U1 | 55
U1 | 56
U1 | 57
U1 | 58 | +3V3
U1 | 59
U1 | 60
U1 | 61
U1 | 62
U1 | 63
U1 | 64 | +3V3
U1 | 65 | GND
U1 | 66 | +1V2
U1 | 67 | +3V3
U1 | 68 | FPGA_RX
U1 | 69 | FPGA_TX
U1 | 70 | ADC_PD
U1 | 71 | STATUS_LED
U1 | 72 | TRIG_OUT
U1 | 73 | USER_IN
U1 | 74
U1 | 75
U1 | 76
U1 | 77
U1 | 78 | +3V3
U1 | 79
U1 | 80
U1 | 81
U1 | 82
U1 | 83
U1 | 84
U1 | 85
U1 | 86
U1 | 87 | FPGA_MODE1
U1 | 88 | FPGA_MODE0
U1 | 89 | GND
U2 | 1 | ADC_VREF
U2 | 2 | ADC_INP
U2 | 3 | ADC_INN
U2 | 4 | GND
U2 | 5 | +5VA
U2 | 6 | +5VA
U2 | 7 | GND
U2 | 8 | ADC_PD
U2 | 9 | GND
U2 | 10 | ADC_CLK
U2 | 11 | GND
U2 | 12 | GND
U2 | 13 | +5VA
U2 | 14 | ADC_RAW_D0
U2 | 15 | ADC_RAW_D1
U2 | 16 | ADC_RAW_D2
U2 | 17 | ADC_RAW_D3
U2 | 18 | ADC_RAW_D4
U2 | 19 | ADC_RAW_D5
U2 | 20 | GND
U2 | 21 | +3V3
U2 | 22 | ADC_RAW_D6
U2 | 23 | ADC_RAW_D7
U2 | 24 | ADC_RAW_D8
U2 | 25 | ADC_RAW_D9
U2 | 26 | ADC_RAW_D10
U2 | 27 | ADC_RAW_D11
U2 | 28 | GND
U2 | 29 | +5VA
U2 | 30 | ADC_VRN
U2 | 31 | ADC_VRP
U2 | 32 | ADC_VRM
U3 | 1 | AD_INN_NODE
U3 | 2 | ADC_VRM
U3 | 3 | +5VA
U3 | 4 | OUT_P_RAW
U3 | 5 | OUT_N_RAW
U3 | 6 | GND
U3 | 7 | AD8137_PD
U3 | 8 | AD_INP_NODE
U4 | 1 | CH347_RST_N
U4 | 2
U4 | 3 | FPGA_RX
U4 | 4 | FPGA_TX
U4 | 5 | CH_JTAG_TMS
U4 | 6 | CH_JTAG_TCK
U4 | 7 | CH_JTAG_TDO
U4 | 8 | CH_JTAG_TDI
U4 | 9
U4 | 10 | CH347_CFG0
U4 | 11
U4 | 12
U4 | 13 | CH347_CFG1
U4 | 14 | +3V3
U4 | 15
U4 | 16 | USB_DM
U4 | 17 | USB_DP
U4 | 18 | GND
U4 | 19 | CH347_XI
U4 | 20 | CH347_XO
U5 | 1 | USB5V
U5 | 2 | GND
U5 | 3 | USB5V
U5 | 4
U5 | 5 | +3V3
U6 | 1 | +3V3
U6 | 2 | GND
U6 | 3 | +3V3
U6 | 4 | +3V3
U6 | 5 | +1V2
U7 | 1 | +5VA
U7 | 2 | ADC_VREF
U7 | 3 | GND
U8 | 1 | VCM_BUF
U8 | 2 | GND
U8 | 3 | ADC_VRM
U8 | 4 | VCM_BUF
U8 | 5 | +5VA
X1 | 1 | OSC_OE
X1 | 2 | GND
X1 | 3 | OSC_OUT
X1 | 4 | +3V3
Y1 | 1 | CH347_XI
Y1 | 2 | GND
Y1 | 3 | CH347_XO
Y1 | 4 | GND

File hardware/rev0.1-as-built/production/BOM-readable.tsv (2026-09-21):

No. | Quantity | Comment | Designator | Footprint | Value | Manufacturer Part | Manufacturer | Supplier Part | Supplier
1 | 10 | CL10A106KP8NNNC | C1,C4,C6,C8,C12,C30,C31,C48,C50,C62 | C0603 | 10uF | CL10A106KP8NNNC | SAMSUNG(三星) | C19702 | LCSC
2 | 4 | CL10A105KB8NNNC | C2,C3,C5,C42 | C0603 | 1uF | CL10A105KB8NNNC | SAMSUNG(三星) | C15849 | LCSC
3 | 28 | CC0603KRX7R9BB104 | C7,C9,C13,C20,C21,C22,C23,C24,C25,C26,C27,C28,C29,C32,C40,C41,C43,C44,C45,C46,C47,C49,C51,C52,C53,C54,C60,C61 | C0603 | 100nF | CC0603KRX7R9BB104 | YAGEO(国巨) | C14663 | LCSC
4 | 2 | TCC0603COG220J500CT | C10,C11 | C0603 | 22pF | TCC0603COG220J500CT | CCTC(三环) | C376775 | LCSC
5 | 1 | TCC0603COG221J500CT | C63 | C0603 | 220pF | TCC0603COG221J500CT | CCTC(三环) | C376776 | LCSC
6 | 1 | USBLC6-2SC6 | D1 | SOT-23-6_L2.9-W1.6-P0.95-LS2.8-BL |  | USBLC6-2SC6 | ST(意法半导体) | C7519 | LCSC
7 | 1 | 19-217/GHC-YR1S2/3T | D2 | LED0603-RD |  | 19-217/GHC-YR1S2/3T | EVERLIGHT(亿光) | C72043 | LCSC
8 | 1 | KT-0603R | D3 | LED-SMD_L1.6-W0.8-R-RD |  | KT-0603R | KENTO | C2286 | LCSC
9 | 1 | SMD1206P050TF | F1 | F1206 |  | SMD1206P050TF |  | C146251 | LCSC
10 | 1 | GZ1608D601TF | FB1 | L0603 |  | GZ1608D601TF | Sunlord(顺络) | C1002 | LCSC
11 | 1 | TYPE-C-31-M-12 | J1 | USB-C_SMD-TYPE-C-31-M-12_1 |  | TYPE-C-31-M-12 | 韩国韩荣 | C165948 | LCSC
12 | 2 | 0603WAF5101T5E | R1,R2 | R0603 | 5.1kΩ | 0603WAF5101T5E | UNI-ROYAL(厚声) | C23186 | LCSC
13 | 12 | 0603WAF1002T5E | R3,R4,R5,R20,R21,R22,R23,R24,R40,R43,R68,R80 | R0603 | 10kΩ | 0603WAF1002T5E | UNI-ROYAL(厚声) | C25804 | LCSC
14 | 2 | 0603WAF1001T5E | R7,R81 | R0603 | 1kΩ | 0603WAF1001T5E | UNI-ROYAL(厚声) | C21190 | LCSC
15 | 8 | 0603WAF330JT5E | R8,R9,R10,R11,R41,R42,R69,R70 | R0603 | 33Ω | 0603WAF330JT5E | UNI-ROYAL(厚声) | C23140 | LCSC
16 | 12 | 0603WAF1000T5E | R44,R45,R46,R47,R48,R49,R50,R51,R52,R53,R54,R55 | R0603 | 100Ω | 0603WAF1000T5E | UNI-ROYAL(厚声) | C22775 | LCSC
17 | 1 | 0603WAF1003T5E | R61 | R0603 | 100kΩ | 0603WAF1003T5E | UNI-ROYAL(厚声) | C25803 | LCSC
18 | 2 | PTFR0603B1K00P9 | R62,R63 | R0603 | 1kΩ | PTFR0603B1K00P9 | RESI(开步睿思) | C328422 | LCSC
19 | 2 | PTFR0603B10K0P9 | R64,R65 | R0603 | 10kΩ | PTFR0603B10K0P9 | RESI(开步睿思) | C328421 | LCSC
20 | 1 | TS-1187A-B-A-B | S1 | SW-SMD_4P-L5.1-W5.1-P3.70-LS6.5-TL_H1.5 |  | TS-1187A-B-A-B | XKB Connection(中国星坤) | C318884 | LCSC
21 | 1 | GW1N-LV4QN88C6/I5 | U1 | QFN-88_L10.0-W10.0-P0.40-BL-EP6.75 |  | GW1N-LV4QN88C6/I5 | GOWIN(高云) | C31900351 | LCSC
22 | 1 | ADC12010CIVYX/NOPB | U2 | LQFP-32_L7.0-W7.0-P0.80-LS9.0-TL |  | ADC12010CIVYX/NOPB | TI(德州仪器) | C2861065 | LCSC
23 | 1 | AD8137YRZ-REEL7 | U3 | SOIC-8_L4.9-W3.9-P1.27-LS6.0-BL |  | AD8137YRZ-REEL7 | ADI(亚德诺) | C31148 | LCSC
24 | 1 | CH347T | U4 | TSSOP-20_L6.5-W4.4-P0.65-LS6.4-BL |  | CH347T | WCH(南京沁恒) | C5122332 | LCSC
25 | 1 | AP2112K-3.3TRG1 | U5 | SOT-25-5_L2.9-W1.6-P0.95-LS2.8-BL |  | AP2112K-3.3TRG1 | DIODES(美台) | C51118 | LCSC
26 | 1 | SGM2037-1.2XN5G/TR | U6 | SOT-23-5_L2.9-W1.6-P0.95-LS2.8-BR |  | SGM2037-1.2XN5G/TR | SGMICRO(圣邦微) | C5152759 | LCSC
27 | 1 | REF3020AIDBZR | U7 | SOT-23-3_L3.0-W1.7-P0.95-LS2.9-BR |  | REF3020AIDBZR | TI(德州仪器) | C26804 | LCSC
28 | 1 | LMV321IDBVR | U8 | SOT-23-5_L3.0-W1.7-P0.95-LS2.8-BR |  | LMV321IDBVR | TI(德州仪器) | C7972 | LCSC
29 | 1 | SX3M10.000B10F20TNN | X1 | OSC-SMD_4P-L3.2-W2.5-BL | 10MHz | SX3M10.000B10F20TNN | SCTF(星通时频) | C5452682 | LCSC
30 | 1 | 3225 8M 20PF 10PPM | Y1 | CRYSTAL-SMD_4P-L3.2-W2.5-BL | 8MHz | 3225 8M 20PF 10PPM | SOSET(索斯特) | C5181477 | LCSC

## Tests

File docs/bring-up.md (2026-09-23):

# First-board bring-up

This procedure is for the v0.1 prototype after applying the mandatory errata.
Do not connect a detector during the initial checks.

## Before power

1. Read `hardware-errata-v0.1.md`.
2. Leave S1 unpopulated.
3. Fit `MCP6001T-I/OT` at U8, or remove U8 and apply the documented temporary
   `ADC_VRM` to `VCM_BUF` bridge. Never leave the bridge in place with an
   active U8 output.
4. Inspect U1, U2, U3, U4, the USB-C connector, and all fine-pitch joints under
   magnification.
5. Confirm there is no low-resistance short from USB5V, +3V3, +1V2, or +5VA to
   ground.
6. Keep J2 open. The input is low-voltage only.

## Limited first power

Use a current-limited 5 V source through a USB power breakout while the
computer is disconnected. Verify:

- USB5V is near 5 V;
- +3V3 is near 3.3 V;
- +1V2 is near 1.2 V;
- +5VA follows the USB supply after the ferrite bead;
- the regulators and FPGA do not heat abnormally.

Fit the originally specified **SGM2037-1.2XN5G/TR** at U6 for a new build. A
prototype fitted with AP2112K-1.2 was later verified to start successfully
without added output capacitance, although that device is not the recommended
production population. Do not add capacitance by default. Only consider a
parallel output capacitor if oscilloscope measurements confirm that an
excessively fast +1V2 rise causes FPGA configuration or startup failure. If a
substitute or extra capacitance is used, characterize +1V2 rise time,
overshoot, regulator stability, and repeatable FPGA configuration.

## USB and FPGA

Connect the board to the host and check that the CH347T enumerates as USB
`1a86:55dd`. Then, from `firmware/mca-v1`:

```sh
make detect
openFPGALoader -c ch347_jtag --freq 1000000 -m \
  prebuilt/aster-mca-v1.9.fs
python3 astermca.py info
python3 astermca.py stats
```

A healthy open-input board should report an ADC baseline near midscale, about
2048. On the validated prototype it was approximately 2033 with a quiet range
near 2029–2039. A baseline stuck at 0 or 4095 is a fault; do not compensate for
it in software.

## Analog checks

With a repaired U8 path and the BNC open, verify approximately:

- C54 non-ground pad (`ADC_VRM`): 2.5 V;
- R63 VCM-side pad (`VCM_BUF`): 2.5 V;
- both C63 ADC input pads: near 2.5 V and within tens of millivolts;
- ADC baseline: near code 2048, not at either rail.

Apply only a small, controlled, low-voltage pulse first. Confirm polarity,
threshold behavior, and the absence of clipping before connecting a real
amplified detector module.

## Detector connection

J2 accepts an already-conditioned low-voltage signal. It does not accept PMT
high voltage or a detector bias line. Use a properly grounded BNC shell and
short coaxial return path. Start with the detector source removed and acquire a
background spectrum before placing a check source.

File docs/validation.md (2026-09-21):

# Prototype validation record

## Setup

- Hardware: repaired Aster MCA v0.1 prototype.
- Firmware: v1.3 loaded into FPGA SRAM.
- Detector: amplified 1-inch NaI(Tl)/PMT module.
- Source: Cs-137 check source in a repeatable nearby position.
- Pulse polarity: negative-going ADC codes.
- Trigger threshold: 32 ADC codes.
- Analog gain: approximately ×3.33, using matched 4.99 kohm R66/R67 in
  parallel with the fitted 10.0 kohm feedback pair.
- Source live time: 943.493 s.
- Background live time: 30.017 s.

## Raw statistics

| Quantity | Source | Background |
| --- | ---: | ---: |
| Saved events | 237943 | 2333 |
| Count rate | 252.19 counts/s | 77.72 counts/s |
| Net source rate | 174.47 counts/s | — |
| Histogram drops | 0 | 0 |

The source acquisition reported 294804 triggers, 237942 accepted events,
56862 rejected events, and 6562 saturated events. The one-count difference
between the statistics snapshot and saved histogram is consistent with an
event arriving between the two host reads.

## Spectrum result

The source and background spectra were normalized by FPGA live time. After
background subtraction, the full-energy feature was centered near channel
95.8. A five-bin smoothing pass and a linear local-continuum estimate gave a
preliminary FWHM of about 11.0 channels, or approximately 11.5% at the assumed
662 keV Cs-137 line.

This is an engineering validation, not a calibrated spectroscopy claim:

- only one known gamma line was available;
- the background run was much shorter than the source run;
- source geometry was not metrologically fixed;
- BNC grounding and the U8 repair were still prototype arrangements;
- the calculation did not perform a full detector-response fit.

The important result is that the independent source and background runs show
a stable, source-dependent peak with zero histogram drops and a baseline that
remained near midscale.

Source, background, and net spectrum

Raw files:

- `examples/cs137/source-943s.csv`
- `examples/cs137/background-30s.csv`

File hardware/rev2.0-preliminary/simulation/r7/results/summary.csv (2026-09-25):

range | gain_v_per_v | baseline_diff_v | overshoot_percent | settling_1pct_us | bandwidth_3db_hz | overload_diff_min_v | overload_diff_max_v | overload_late_residual_mv | estimated_input_current_at_2p7v_ma
0p5x | 0.50005765202 | 0.000567140204 | 0.00045534749659736917 | 0.43867656000000005 | 1647947.9173281288 | -1.34959467 | 0.000567144756 | 0.0 | 0.675219446320054
5x | 4.9686721175 | 0.006087199 | 0.00043970500533951906 | 0.44125205000000006 | 1656244.6001779225 | -0.521478993 | 0.00608725647 | nan | 6.704742984852248
25x | 25.3922959375 | 0.0185878349 | 0.0003256401083451266 | 0.4538453900000001 | 1564136.4064031504 | -0.219337654 | 0.0185880114 | nan | 34.30749682337993

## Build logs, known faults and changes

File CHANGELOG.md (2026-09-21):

# Changelog

## Unreleased

- Prepared a public repository layout and documented the v0.1 hardware errata.
- Added measured Cs-137 and background example data.
- Added a prebuilt FPGA v1.3 SRAM image and reproducible tests.
- Renamed the public project to Aster MCA while preserving legacy CAD titles
  inside the manufactured v0.1 evidence files.
- Marked SGM2037-1.2 as the recommended U6, recorded successful AP2112K-1.2
  startup without added capacitance, and limited extra capacitance to a
  measurement-confirmed fast-ramp recovery case.
- Added a single-image overview of all five v0.1 schematic sheets to both
  repository home pages.
- Added an explicit AI-assisted development disclosure.
- Documented the R62-R67 gain network, including the physically validated
  matched 4.99 kohm R66/R67 population for nominal gain about ×3.33.

## Firmware v1.3 — 2026-09-21

- Prevented large opposite-polarity excursions from dragging the tracked
  baseline to an ADC rail.
- Added a 1 ms recovery interval after saturated events.
- Retained an 8-sample recovery interval after normal events.
- Added regression coverage for rail-sized opposite-polarity excursions.

## Firmware v1.2 — 2026-09-21

- Selected negative-going pulses by default.
- Set the default threshold to 32 ADC codes.
- Corrected histogram/statistics clear priority so live time resets reliably.
- Clarified pulse-polarity reporting in the host utility.

## Hardware v0.1 — 2026-09-16

- First manufactured four-layer FPGA MCA prototype.
- Native EasyEDA Pro project, Gerber, BOM, and placement data archived.
- Requires the U8 and S1 corrections documented in
  `docs/hardware-errata-v0.1.md`.

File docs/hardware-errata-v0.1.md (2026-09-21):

# Hardware v0.1 errata

This document applies to boards manufactured from
`hardware/rev0.1-as-built/production`. The archived files are the exact design
lineage used for the first boards and are intentionally not silently replaced
with a different revision.

## E1 — U8 pin-map mismatch (mandatory fix)

The PCB net map assumes U8 is a voltage follower with this SOT-23-5 pinout:

| Pad | Required function |
| ---: | --- |
| 1 | OUT / `VCM_BUF` |
| 2 | GND |
| 3 | IN+ / `ADC_VRM` |
| 4 | IN- / `VCM_BUF` |
| 5 | +5VA |

The v0.1 BOM instead specifies TI `LMV321IDBVR`, whose pins are 1 IN+, 2 GND,
3 IN-, 4 OUT, 5 V+. Fitting that part creates positive feedback and drives the
analog common-mode node to a rail. The observed failure signature was
`VCM_BUF` near 5.13 V and the ADC stuck at code 4095.

### Preferred repair

Fit **`MCP6001T-I/OT`** in U8. Its plain SOT-23-5 variant matches the PCB net
map: 1 OUT, 2 VSS, 3 IN+, 4 IN-, 5 VDD.

Do not use MCP6001R or MCP6001U suffix variants; their pin maps differ.

### Temporary bring-up bypass

With power removed:

1. remove U8 completely;
2. bridge C54 pin 1 / non-ground pad (`ADC_VRM`) to the VCM side of R63
   (`VCM_BUF`) with a short insulated wire;
3. check that neither endpoint is shorted to ground or +5VA before power-up.

The ADC12010 VRM output can supply the small DC common-mode load used here,
and this bypass was sufficient for prototype validation. It is not the
preferred low-noise final implementation.

**Never install this bridge while U8 remains active.** The op-amp output would
fight the ADC reference node.

## E2 — S1 switch contact pairing (mandatory fix)

Leave S1 unpopulated. The v0.1 PCB assigns opposite footprint numbers to
`RECONFIG_N` and GND, but the selected four-pin tactile switch internally pairs
contacts in a way that can hold `RECONFIG_N` low. The result is a board that
enumerates through CH347T but does not configure the FPGA reliably.

The first boards configured normally after S1 was removed. Use J3 or a future
corrected footprint if a manual reconfiguration input is required.

## E3 — Analog gain population

The archived BOM fits R64 and R65 as 10.0 kohm and leaves R66/R67 unpopulated,
giving a nominal differential gain magnitude of 10 with R62/R63 = 1.00 kohm.

R66 is directly in parallel with R64, and R67 is directly in parallel with
R65. They are not series positions or independent channel controls. Both must
be left open or populated with the same value:

```text
RF+ = R64 || R66
RF- = R65 || R67
Gain ≈ RF / RG, with R62 = R63 = RG = 1.00 kohm
```

The reported Cs-137 validation populated **4.99 kohm, 0.1%** at both R66 and
R67 in parallel with the fitted 10.0 kohm pair. The effective feedback
resistance was about 3.33 kohm, for a gain near ×3.33. Both sides must remain
matched. Gain changes alter input range, clipping behavior, and calibration.
The detailed population table and the roles of R60/R61/R69/R70 are documented
in [`gain-configuration.md`](gain-configuration.md).

## E4 — Restore the original U6 regulator for new builds

Fit the originally specified **`SGM2037-1.2XN5G/TR`** at U6 for a new build. A
board assembled with a factory-substituted `AP2112K-1.2` was later verified to
start successfully without added output capacitance, so extra capacitance is
not an inherent requirement of that substitute. The AP2112K remains a tested
prototype substitution rather than the recommended production population.

Only consider parallel output capacitance if oscilloscope measurements confirm
that an excessively fast +1V2 rise is causing FPGA configuration or startup
failure. If it is added, verify the regulator's allowed output-capacitance and
ESR range, rise time, overshoot, loop stability, current limit, and repeatable
FPGA configuration. For any substitute, first verify pinout and enable logic.

## Post-repair acceptance checks

With the BNC open and v1.3 firmware loaded:

1. `ADC_VRM` is approximately 2.5 V.
2. `VCM_BUF` is approximately 2.5 V.
3. Both ADC inputs are near 2.5 V.
4. ADC baseline is near midscale and not at 0 or 4095.
5. The heartbeat LED runs after SRAM configuration.
6. A small safe test pulse produces the expected polarity without clipping.

Only after these checks should an amplified detector module be connected.

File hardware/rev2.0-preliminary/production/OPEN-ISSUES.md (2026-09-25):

# Open issues for r8

The current board is fully routed and the fresh PCB DRC, schematic ERC and
independent PCB/manifest audit are clean. The design remains on hold for:

1. exact-device MAX 10 Quartus pin-legality and timing compilation;
2. FPGA firmware and RP2350 host firmware;
3. a 1:1 physical overlay of the exact RP2350 clone;
4. continuity and position verification of the purchased DP3T switch;
5. real ADS5560 input-load, clock/data timing and power-integrity measurements;
6. safe overload/recovery validation, particularly in the 25x range;
7. exact purchasable-part binding and a final native EasyEDA/JLCPCB assembly
   review.

The files in `quote-r8-current-source/` are deliberately for quotation only.

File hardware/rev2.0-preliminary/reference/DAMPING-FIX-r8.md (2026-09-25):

# Aster MCA v2.0 r8 output-damping correction

Date: 2026-09-25

## Applied change

- R9: `10R 1%` -> `22R 1%`
- R10: `10R 1%` -> `22R 1%`
- No nets, footprints, placement, routing, copper geometry, or other component values were changed.
- The source schematic, source PCB, `parts-manifest.json`, and current reference BOM were updated together.

R9 and R10 are the two symmetrical series resistors between the THS4551 outputs and the ADS5560 differential inputs. The change increases isolation between the FDA and the ADC input capacitor C2.

## Why it was changed

With the previous 10 ohm value, the TI THS4551 macro-model and the present 2.2 nF C2 load showed an underdamped output network in the 0.5x range:

| Configuration | AC peaking | Peak frequency | Post-pulse differential ringing | 1% settling |
|---|---:|---:|---:|---:|
| Previous 10 ohm | 9.742 dB | 35.48 MHz | 108.4 mVpp | Did not settle in the simulated window |
| Current 22 ohm | 0.000 dB | None observed | < 1 nVpp | 0.439 us |

The 22 ohm option is the lowest tested value that removed the simulated peaking and sustained ringing without the bandwidth and pulse-height loss seen with larger values.

## Post-fix range simulation

The default board simulation was rerun with R9 = R10 = 22 ohm:

| Range | Simulated gain | -3 dB bandwidth | AC peaking | 1% settling | Post-pulse ringing |
|---|---:|---:|---:|---:|---:|
| 0.5x | 0.50006 V/V | 1.648 MHz | 0.000 dB | 0.439 us | < 1 nVpp |
| 5x | 4.96867 V/V | 1.656 MHz | 0.000 dB | 0.441 us | < 1 nVpp |
| 25x | 25.39230 V/V | 1.564 MHz | 0.000 dB | 0.454 us | < 1 nVpp |

These results use TI's THS4551 PSpice macro-model. They do not model the ADS5560 switched-capacitor input exactly, so first-power-up oscilloscope verification remains required.

## CAD and connectivity verification

- Schematic ERC: 0 violations.
- PCB DRC: 0 violations, 0 unconnected items, 0 footprint errors.
- Static schematic/PCB/manifest connectivity audit: PASS.
- Critical maps for R9, R10, C2, ADC clock, and FPGA clock interfaces remain unchanged and correct.

## Release status

This correction is present in the editable source files. The older frozen production candidate packages were intentionally not regenerated and must not be ordered as r8. A fresh production export should only be made after the exact Quartus project compiles and the remaining physical switch and ADC-input bench checks are complete.

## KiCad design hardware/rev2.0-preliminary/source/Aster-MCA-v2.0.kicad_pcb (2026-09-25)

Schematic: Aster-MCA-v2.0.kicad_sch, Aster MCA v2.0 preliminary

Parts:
A1: RP2350 Pico 2 compatible 52x21mm; RP2350_Clone_52x21mm_Castellated
C1: 100n FILM DNP; Capacitor_THT__C_Rect_L7.2mm_W2.5mm_P5.00mm__AsterProd; not fitted
C2: 2.2n C0G; Capacitor_SMD__C_0603_1608Metric__AsterProd
C5, C7, C9, C10, C11, C12, C13, C14, C15, C16, C17, C18, C19, C20, C21, C22, C23, C24, C30, C31, C32, C33, C34, C35, C36, C37, C42: 100n; Capacitor_SMD__C_0603_1608Metric__AsterProd
C6: 2.2u; Capacitor_SMD__C_0805_2012Metric_Pad1.18x1.45mm_HandSolder_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
C8: 1u; Capacitor_SMD__C_0805_2012Metric_Pad1.18x1.45mm_HandSolder_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
C25, C26, C27, C29: 4.7u; Capacitor_SMD__C_0805_2012Metric_Pad1.18x1.45mm_HandSolder_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
C28: 10u; Capacitor_SMD__C_0805_2012Metric_Pad1.18x1.45mm_HandSolder_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
C38: 100n; Capacitor_SMD__C_0402_1005Metric__AsterProd
C39: 10u 10V; Capacitor_SMD__C_1206_3216Metric_Pad1.33x1.80mm_HandSolder_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
C40, C41: 22u 6.3V; Capacitor_SMD__C_1206_3216Metric_Pad1.33x1.80mm_HandSolder_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
D1: PESD5V0S1UL DNP; Diode_SMD__D_SOD-323_HandSoldering__AsterProd; not fitted
D2: PWR; LED_THT__LED_D3.0mm__AsterProd
D3: RUN; LED_THT__LED_D3.0mm__AsterProd
D4: TRIG; LED_THT__LED_D3.0mm__AsterProd
D5: SAT; LED_THT__LED_D3.0mm__AsterProd
D6: SS14L USB OR; Diode_SMD__D_SOD-123F__AsterProd
D7: SS14L EXT OR; Diode_SMD__D_SOD-123F__AsterProd
F1: 1.5A RESETTABLE; Fuse__Fuse_1206_3216Metric_Pad1.42x1.75mm_HandSolder__Aster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
FB1, FB2, FB3, FB4: 600R@100MHz 1A; Inductor_SMD__L_0805_2012Metric_Pad1.05x1.20mm_HandSolder__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
J1: BNC INPUT; Connector_Coaxial__BNC_Amphenol_031-5539_Vertical__AsterProd
J2: INTEL JTAG; Connector_PinHeader_2.54mm__PinHeader_2x05_P2.54mm_Vertical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
J3: EXT TRIG; Connector_PinHeader_2.54mm__PinHeader_1x03_P2.54mm_Vertical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
J4: ALT 5V IN; Connector_PinHeader_2.54mm__PinHeader_1x02_P2.54mm_Vertical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
JP1: 50R TERM; Connector_PinHeader_2.54mm__PinHeader_1x02_P2.54mm_Vertical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
JP2: DC / AC; Connector_PinHeader_2.54mm__PinHeader_1x03_P2.54mm_Vertical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
L1: 3.9uH >=3A; Inductor_SMD__L_Changjiang_FNR6020S__AsterProd
R1: 49R9 0.1% DNP; Resistor_SMD__R_0805_2012Metric_Pad1.20x1.40mm_HandSolder__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; not fitted
R2, R4: 78R7 0.1%; Resistor_SMD__R_0805_2012Metric_Pad1.20x1.40mm_HandSolder__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
R3: 0R; Resistor_SMD__R_0805_2012Metric_Pad1.20x1.40mm_HandSolder__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
R5: 3k92 0.1%; Resistor_SMD__R_0805_2012Metric_Pad1.20x1.40mm_HandSolder__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
R6: 4k00 0.1%; Resistor_SMD__R_0805_2012Metric_Pad1.20x1.40mm_HandSolder__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
R7, R8: 2k00 0.1%; Resistor_SMD__R_0805_2012Metric_Pad1.20x1.40mm_HandSolder__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
R9, R10: 22R 1%; Resistor_SMD__R_0805_2012Metric__AsterProd
R11, R14, R33, R34, R35, R37, R38, R39, R40, R41: 10k; Resistor_SMD__R_0805_2012Metric_Pad1.20x1.40mm_HandSolder__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
R12: 8k25 1%; Resistor_SMD__R_0805_2012Metric_Pad1.20x1.40mm_HandSolder__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
R13: 4k99 1%; Resistor_SMD__R_0805_2012Metric_Pad1.20x1.40mm_HandSolder__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
R15, R16: 33R; Resistor_SMD__R_0805_2012Metric_Pad1.20x1.40mm_HandSolder__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
R36, R42, R43, R44, R45: 1k; Resistor_SMD__R_0805_2012Metric_Pad1.20x1.40mm_HandSolder__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
R46: 324R 0.1%; Resistor_SMD__R_0805_2012Metric_Pad1.20x1.40mm_HandSolder__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
R47: 402R 0.1%; Resistor_SMD__R_0805_2012Metric_Pad1.20x1.40mm_HandSolder__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
RN1, RN2, RN3, RN4: 33R x4 isolated; Resistor_SMD__R_Array_Convex_4x0603__AsterProd
SW1: GAIN 0.5x / 5x / 25x; Button_Switch_THT__SW_CK_JS203011AQN_DP3T_Angled__AsterProd
SW2: FPGA RECONFIG; Button_Switch_THT__SW_Tactile_SPST_Angled_PTS645Vx39-2LFS__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
TP1: TP_GND; TestPoint__TestPoint_Plated_Hole_D2.0mm__AsterProd
TP2: TP_5V; TestPoint__TestPoint_Plated_Hole_D2.0mm__AsterProd
TP3: TP_3V3D; TestPoint__TestPoint_Plated_Hole_D2.0mm__AsterProd
TP4: TP_3V3A; TestPoint__TestPoint_Plated_Hole_D2.0mm__AsterProd
TP5: TP_VCM; TestPoint__TestPoint_Plated_Hole_D2.0mm__AsterProd
U1: 10M16SAE144C8G; Package_QFP__EQFP-144-1EP_20x20mm_P0.5mm_EP4x4mm__AsterProd
U2: ADS5560IRGZT; Package_DFN_QFN__Texas_RGZ0048A_VQFN-48-1EP_7x7mm_P0.5mm_EP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
U3: THS4551IDGKT; Package_SO__VSSOP-8_3x3mm_P0.65mm__AsterProd
U4: AP63203WU-7; Package_TO_SOT_SMD__TSOT-23-6_HandSoldering__AsterProd
Y1: 40.000 MHz CMOS; Oscillator__Oscillator_SMD_Abracon_ASE-4Pin_3.2x2.5mm_HandS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

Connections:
3V3_A: C28.1 (3V3_A), C30.1 (3V3_A), C32.1 (3V3_A), C33.1 (3V3_A), C34.1 (3V3_A), C35.1 (3V3_A), FB2.2 (3V3_A), TP4.1, U2.8 (3V3_A), U2.18 (3V3_A), U2.20 (3V3_A), U2.22 (3V3_A), U2.24 (3V3_A), U2.26 (3V3_A)
3V3_D: C11.1 (3V3_D), C12.1 (3V3_D), C13.1 (3V3_D), C14.1 (3V3_D), C15.1 (3V3_D), C16.1 (3V3_D), C17.1 (3V3_D), C18.1 (3V3_D), C19.1 (3V3_D), C20.1 (3V3_D), C25.1 (3V3_D), C27.1 (3V3_D), C29.1 (3V3_D), C31.1 (3V3_D), C36.1 (3V3_D), C37.1 (3V3_D), C42.1 (3V3_D), D2.2 (3V3_D), FB1.2 (3V3_D), J2.4 (3V3_D), J3.1 (3V3_D), R12.1 (3V3_D), R14.1 (3V3_D), R33.1 (3V3_D), R34.1 (3V3_D), R35.1 (3V3_D), R37.1 (3V3_D), R38.1 (3V3_D), R39.1 (3V3_D), R40.1 (3V3_D), R41.1 (3V3_D), TP3.1, U1.9 (3V3_D), U1.23 (3V3_D), U1.31 (3V3_D), U1.40 (3V3_D), U1.49 (3V3_D), U1.67 (3V3_D), U1.82 (3V3_D), U1.94 (3V3_D), U1.103 (3V3_D), U1.117 (3V3_D), U1.128 (3V3_D), U1.139 (3V3_D), U2.2 (3V3_D), U2.7 (3V3_D), U2.27 (3V3_D), U2.30 (3V3_D), U2.35 (3V3_D), Y1.4 (3V3_D)
3V3_FPGA_A: C21.1 (3V3_FPGA_A), C22.1 (3V3_FPGA_A), C23.1 (3V3_FPGA_A), C24.1 (3V3_FPGA_A), C26.1 (3V3_FPGA_A), FB3.2 (3V3_FPGA_A), U1.1 (3V3_FPGA_A), U1.2 (3V3_FPGA_A), U1.34 (3V3_FPGA_A), U1.35 (3V3_FPGA_A), U1.36 (3V3_FPGA_A), U1.37 (3V3_FPGA_A), U1.51 (3V3_FPGA_A), U1.71 (3V3_FPGA_A), U1.72 (3V3_FPGA_A), U1.73 (3V3_FPGA_A), U1.107 (3V3_FPGA_A), U1.108 (3V3_FPGA_A), U1.109 (3V3_FPGA_A), U1.115 (3V3_FPGA_A), U1.143 (3V3_FPGA_A), U1.144 (3V3_FPGA_A)
3V3_RAW: C40.1 (3V3_RAW), C41.1 (3V3_RAW), FB1.1 (3V3_RAW), FB2.1 (3V3_RAW), FB3.1 (3V3_RAW), L1.2 (3V3_RAW), U4.1 (3V3_RAW)
5VA: C5.1 (5VA), C6.1 (5VA), FB4.2 (5VA), R11.1 (5VA), U3.3 (5VA)
5V_FUSED: C39.1 (5V_FUSED), D6.1 (5V_FUSED), D7.1 (5V_FUSED), FB4.1 (5V_FUSED), TP2.1, U4.2 (5V_FUSED), U4.3 (5V_FUSED)
ADC_CLKM: C9.1 (ADC_CLKM), U2.11 (ADC_CLKM)
ADC_CLKOUT: R16.1 (ADC_CLKOUT), U2.5 (ADC_CLKOUT)
ADC_CLKP: C10.2 (ADC_CLKP), U2.10 (ADC_CLKP)
ADC_D0: RN4.4 (ADC_D0), U2.31 (ADC_D0)
ADC_D1: RN4.3 (ADC_D1), U2.32 (ADC_D1)
ADC_D2: RN4.2 (ADC_D2), U2.33 (ADC_D2)
ADC_D3: RN4.1 (ADC_D3), U2.34 (ADC_D3)
ADC_D4: RN3.4 (ADC_D4), U2.37 (ADC_D4)
ADC_D5: RN3.3 (ADC_D5), U2.38 (ADC_D5)
ADC_D6: RN3.2 (ADC_D6), U2.39 (ADC_D6)
ADC_D7: RN3.1 (ADC_D7), U2.40 (ADC_D7)
ADC_D8: RN2.4 (ADC_D8), U2.41 (ADC_D8)
ADC_D9: RN2.3 (ADC_D9), U2.42 (ADC_D9)
ADC_D10: RN2.2 (ADC_D10), U2.43 (ADC_D10)
ADC_D11: RN2.1 (ADC_D11), U2.44 (ADC_D11)
ADC_D12: RN1.4 (ADC_D12), U2.45 (ADC_D12)
ADC_D13: RN1.3 (ADC_D13), U2.46 (ADC_D13)
ADC_D14: RN1.2 (ADC_D14), U2.47 (ADC_D14)
ADC_D15: RN1.1 (ADC_D15), U2.48 (ADC_D15)
ADC_DFS: R12.2 (ADC_DFS), R13.1 (ADC_DFS), U2.6 (ADC_DFS)
ADC_INM: C2.2 (ADC_INM), R9.2 (ADC_INM), U2.16 (ADC_INM)
ADC_INP: C2.1 (ADC_INP), R10.2 (ADC_INP), U2.15 (ADC_INP)
ADC_OVR: U1.69 (ADC_OVR), U2.3 (ADC_OVR)
ADC_VCM: C7.1 (ADC_VCM), C8.1 (ADC_VCM), TP5.1, U2.13 (ADC_VCM), U3.2 (ADC_VCM)
AFE_AC: C1.2 (AFE_AC), JP2.3 (AFE_AC)
AFE_IN: C1.1 (AFE_IN), D1.2 (AFE_IN), JP2.1 (AFE_IN), R2.2 (AFE_IN)
ALT_5V_IN: D7.2 (ALT_5V_IN), J4.1 (ALT_5V_IN)
BUCK_BST: C38.1 (BUCK_BST), U4.6 (BUCK_BST)
BUCK_SW: C38.2 (BUCK_SW), L1.1 (BUCK_SW), U4.5 (BUCK_SW)
CLK40_RAW: C10.1 (CLK40_RAW), R15.1 (CLK40_RAW), Y1.3 (CLK40_RAW)
CLK_OE: R14.2 (CLK_OE), Y1.1 (CLK_OE)
CONF_DONE: R39.2 (CONF_DONE), U1.138 (CONF_DONE)
EXT_TRIG: A1.22 (EXT_TRIG), J3.2 (EXT_TRIG), R41.2 (EXT_TRIG), U1.93 (EXT_TRIG)
FDA_INN: R3.2 (FDA_INN), R5.2 (FDA_INN), R7.2 (FDA_INN), R46.2 (FDA_INN), U3.1 (FDA_INN)
FDA_INP: R4.2 (FDA_INP), R6.2 (FDA_INP), R8.2 (FDA_INP), R47.2 (FDA_INP), U3.8 (FDA_INP)
FDA_OUTN: R8.1 (FDA_OUTN), R10.1 (FDA_OUTN), U3.5 (FDA_OUTN)
FDA_OUTP: R7.1 (FDA_OUTP), R9.1 (FDA_OUTP), U3.4 (FDA_OUTP)
FDA_PD: R11.2 (FDA_PD), U3.7 (FDA_PD)
FPGA_ADCCLK: R16.2 (FPGA_ADCCLK), U1.58 (FPGA_ADCCLK)
FPGA_ADC_D0: RN4.5 (FPGA_ADC_D0), U1.62 (FPGA_ADC_D0)
FPGA_ADC_D1: RN4.6 (FPGA_ADC_D1), U1.61 (FPGA_ADC_D1)
FPGA_ADC_D2: RN4.7 (FPGA_ADC_D2), U1.60 (FPGA_ADC_D2)
FPGA_ADC_D3: RN4.8 (FPGA_ADC_D3), U1.59 (FPGA_ADC_D3)
FPGA_ADC_D4: RN3.5 (FPGA_ADC_D4), U1.64 (FPGA_ADC_D4)
FPGA_ADC_D5: RN3.6 (FPGA_ADC_D5), U1.54 (FPGA_ADC_D5)
FPGA_ADC_D6: RN3.7 (FPGA_ADC_D6), U1.52 (FPGA_ADC_D6)
FPGA_ADC_D7: RN3.8 (FPGA_ADC_D7), U1.50 (FPGA_ADC_D7)
FPGA_ADC_D8: RN2.5 (FPGA_ADC_D8), U1.47 (FPGA_ADC_D8)
FPGA_ADC_D9: RN2.6 (FPGA_ADC_D9), U1.46 (FPGA_ADC_D9)
FPGA_ADC_D10: RN2.7 (FPGA_ADC_D10), U1.45 (FPGA_ADC_D10)
FPGA_ADC_D11: RN2.8 (FPGA_ADC_D11), U1.44 (FPGA_ADC_D11)
FPGA_ADC_D12: RN1.5 (FPGA_ADC_D12), U1.43 (FPGA_ADC_D12)
FPGA_ADC_D13: RN1.6 (FPGA_ADC_D13), U1.41 (FPGA_ADC_D13)
FPGA_ADC_D14: RN1.7 (FPGA_ADC_D14), U1.39 (FPGA_ADC_D14)
FPGA_ADC_D15: RN1.8 (FPGA_ADC_D15), U1.38 (FPGA_ADC_D15)
FPGA_REFCLK: R15.2 (FPGA_REFCLK), U1.56 (FPGA_REFCLK)
FPGA_RESET_N: A1.21 (FPGA_RESET_N), R40.2 (FPGA_RESET_N), U1.92 (FPGA_RESET_N)
FPGA_RUN: D3.2 (FPGA_RUN), U1.110 (FPGA_RUN)
FPGA_SAT: D5.2 (FPGA_SAT), U1.120 (FPGA_SAT)
FPGA_TRIG: D4.2 (FPGA_TRIG), U1.111 (FPGA_TRIG)
GAIN_H_GND: R4.1 (GAIN_H_GND), SW1.5 (GAIN_H_GND)
GAIN_H_SIG: R3.1 (GAIN_H_SIG), SW1.1 (GAIN_H_SIG)
GAIN_L_GND: R6.1 (GAIN_L_GND), SW1.8 (GAIN_L_GND)
GAIN_L_SIG: R5.1 (GAIN_L_SIG), SW1.4 (GAIN_L_SIG)
GAIN_M_GND: R47.1 (GAIN_M_GND), SW1.6 (GAIN_M_GND)
GAIN_M_SIG: R46.1 (GAIN_M_SIG), SW1.2 (GAIN_M_SIG)
GAIN_SRC: JP2.2 (GAIN_SRC), SW1.3 (GAIN_SRC)
GND: A1.3 (GND), A1.8 (GND), A1.13 (GND), A1.18 (GND), A1.23 (GND), A1.28 (GND), A1.33 (GND), A1.38 (GND), C5.2 (GND), C6.2 (GND), C7.2 (GND), C8.2 (GND), C9.2 (GND), C11.2 (GND), C12.2 (GND), C13.2 (GND), C14.2 (GND), C15.2 (GND), C16.2 (GND), C17.2 (GND), C18.2 (GND), C19.2 (GND), C20.2 (GND), C21.2 (GND), C22.2 (GND), C23.2 (GND), C24.2 (GND), C25.2 (GND), C26.2 (GND), C27.2 (GND), C28.2 (GND), C29.2 (GND), C30.2 (GND), C31.2 (GND), C32.2 (GND), C33.2 (GND), C34.2 (GND), C35.2 (GND), C36.2 (GND), C37.2 (GND), C39.2 (GND), C40.2 (GND), C41.2 (GND), C42.2 (GND), D1.1 (GND), J1.2 (GND), J2.2 (GND), J2.10 (GND), J3.3 (GND), J4.2 (GND), R1.2 (GND), R13.2 (GND), R36.2 (GND), R42.1 (GND), R43.1 (GND), R44.1 (GND), R45.1 (GND), SW1.7 (GND), SW2.2 (GND), TP1.1, U1.3 (GND), U1.4 (GND), U1.42 (GND), U1.53 (GND), U1.63 (GND), U1.68 (GND), U1.83 (GND), U1.95 (GND), U1.104 (GND), U1.116 (GND), U1.125 (GND), U1.133 (GND), U1.137 (GND), U1.142 (GND), U1.145 (GND), U2.1 (GND), U2.9 (GND), U2.12 (GND), U2.14 (GND), U2.17 (GND), U2.19 (GND), U2.23 (GND), U2.25 (GND), U2.28 (GND), U2.29 (GND), U2.36 (GND), U2.49 (GND), U3.6 (GND), U4.4 (GND), Y1.2 (GND)
HOST_AUX: A1.20 (HOST_AUX), U1.91 (HOST_AUX)
HOST_CS: A1.14 (HOST_CS), U1.86 (HOST_CS)
HOST_D0: A1.1 (HOST_D0), U1.81 (HOST_D0)
HOST_D1: A1.2 (HOST_D1), U1.80 (HOST_D1)
HOST_D2: A1.4 (HOST_D2), U1.79 (HOST_D2)
HOST_D3: A1.5 (HOST_D3), U1.78 (HOST_D3)
HOST_D4: A1.6 (HOST_D4), U1.77 (HOST_D4)
HOST_D5: A1.7 (HOST_D5), U1.76 (HOST_D5)
HOST_D6: A1.9 (HOST_D6), U1.75 (HOST_D6)
HOST_D7: A1.10 (HOST_D7), U1.74 (HOST_D7)
HOST_IRQ: A1.15 (HOST_IRQ), U1.87 (HOST_IRQ)
HOST_MISO: A1.19 (HOST_MISO), U1.90 (HOST_MISO)
HOST_MOSI: A1.17 (HOST_MOSI), U1.89 (HOST_MOSI)
HOST_RD: A1.12 (HOST_RD), U1.85 (HOST_RD)
HOST_SCK: A1.16 (HOST_SCK), U1.88 (HOST_SCK)
HOST_WR: A1.11 (HOST_WR), U1.84 (HOST_WR)
JTAGEN: R33.2 (JTAGEN), U1.15 (JTAGEN)
JTAG_TCK: J2.1 (JTAG_TCK), R36.1 (JTAG_TCK), U1.18 (JTAG_TCK)
JTAG_TDI: J2.9 (JTAG_TDI), R35.2 (JTAG_TDI), U1.19 (JTAG_TDI)
JTAG_TDO: J2.3 (JTAG_TDO), U1.20 (JTAG_TDO)
JTAG_TMS: J2.5 (JTAG_TMS), R34.2 (JTAG_TMS), U1.16 (JTAG_TMS)
LED_R1: D2.1 (LED_R1), R42.2 (LED_R1)
LED_R2: D3.1 (LED_R2), R43.2 (LED_R2)
LED_R3: D4.1 (LED_R3), R44.2 (LED_R3)
LED_R4: D5.1 (LED_R4), R45.2 (LED_R4)
NCONFIG: R37.2 (NCONFIG), SW2.1 (NCONFIG), U1.129 (NCONFIG)
NSTATUS: R38.2 (NSTATUS), U1.136 (NSTATUS)
PMT_IN: J1.1 (PMT_IN), JP1.1 (PMT_IN), R2.1 (PMT_IN)
TERM_50: JP1.2 (TERM_50), R1.1 (TERM_50)
USB_5V_PROTECTED: D6.2 (USB_5V_PROTECTED), F1.2 (USB_5V_PROTECTED)
VBUS: A1.40 (VBUS), F1.1 (VBUS)

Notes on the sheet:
ASTER MCA v2.0 — 16-bit / 40 MSPS / MAX 10 / RP2350
PRELIMINARY ENGINEERING SCHEMATIC — NOT RELEASED FOR FABRICATION
Analog gain: LOW ≈0.5x, HIGH ≈20x; both halves of SW1 change together.
ANALOG INPUT / GAIN / ADC SUPPORT
FPGA / HOST SUPPORT
POWER
TEST POINTS

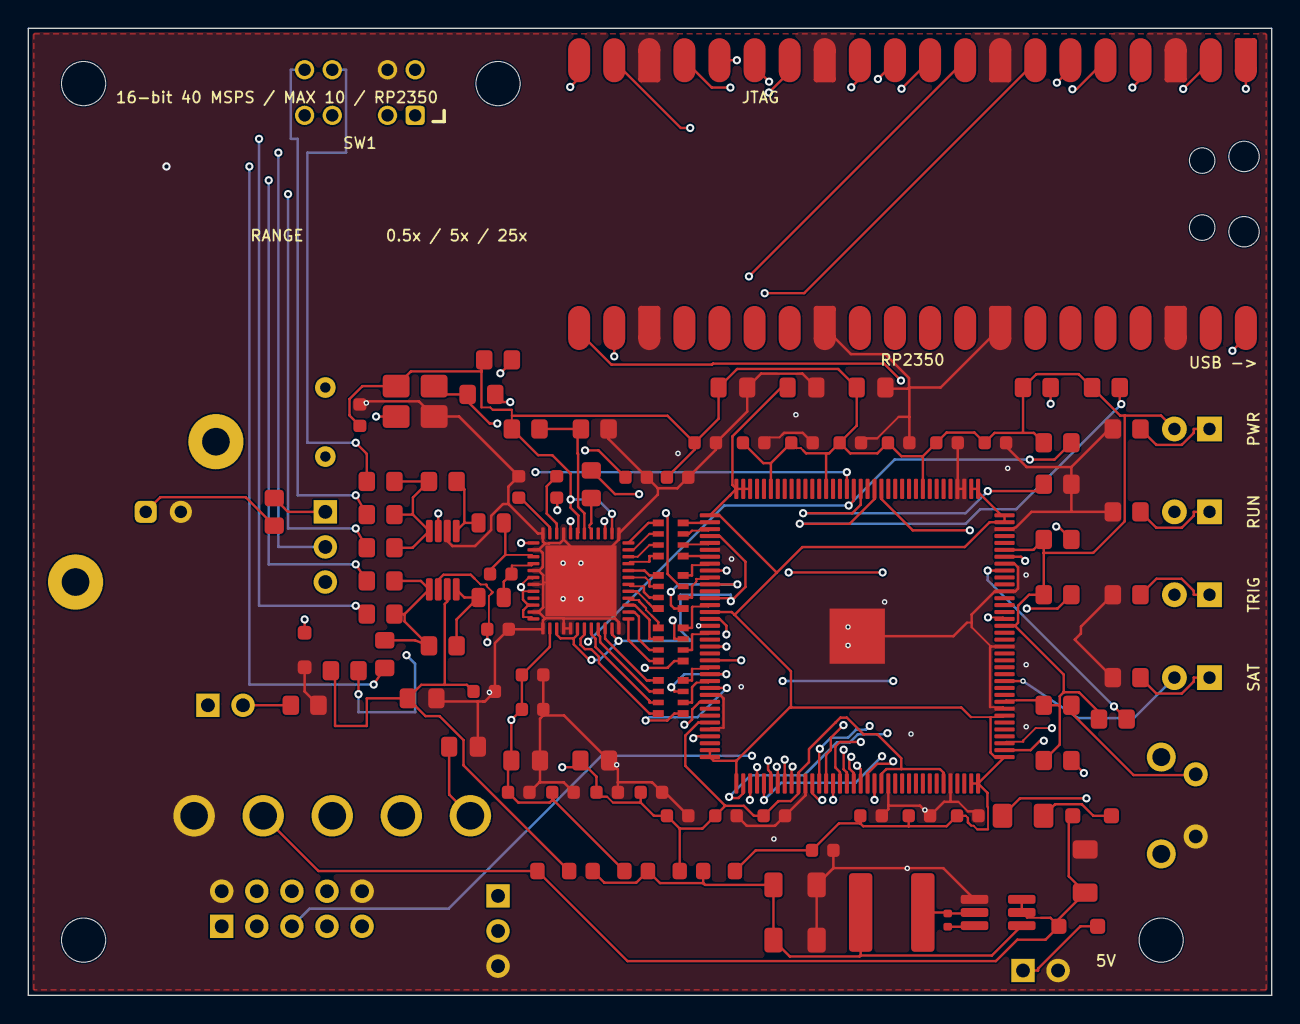
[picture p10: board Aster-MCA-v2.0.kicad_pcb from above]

Board: 4 copper layers, 90.0 x 70.0 mm, 111 parts (0 on the bottom side), 105 nets.

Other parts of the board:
H1, H2, H3, H4: MountingHole_3.2mm_M3; __MountingHole_3.2mm_M3__AsterProd

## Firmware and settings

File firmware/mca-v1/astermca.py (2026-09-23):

#!/usr/bin/env python3
"""Aster MCA v1 host utility for the on-board CH347T UART.

This intentionally uses libusb directly. CH347T mode 3 does not reliably
create a serial device on macOS, but its UART data interface is still usable
through bulk USB endpoints.
"""

from __future__ import annotations

import argparse
import binascii
import csv
import ctypes
import ctypes.util
from dataclasses import dataclass
from datetime import datetime
from pathlib import Path
import struct
import sys
import time
from typing import Iterable, Optional


VID = 0x1A86
PID = 0x55DD
UART_INTERFACE = 1
UART_OUT_ENDPOINT = 0x04
UART_IN_ENDPOINT = 0x84
UART_BAUD = 1_000_000

LIBUSB_SUCCESS = 0
LIBUSB_ERROR_TIMEOUT = -7

MAGIC = b"MCA1"
RESP_INFO = ord("I")
RESP_STATS = ord("S")
RESP_HIST = ord("H")


class AsterMCAError(RuntimeError):
    pass


class USBError(AsterMCAError):
    pass


class ProtocolError(AsterMCAError):
    pass


def crc16_ccitt(data: bytes) -> int:
    """CRC-16/CCITT-FALSE: poly 0x1021, init 0xffff, no reflection."""
    return binascii.crc_hqx(data, 0xFFFF)


def _load_libusb() -> ctypes.CDLL:
    candidates = [
        ctypes.util.find_library("usb-1.0"),
        "/opt/homebrew/opt/libusb/lib/libusb-1.0.dylib",
        "/opt/homebrew/lib/libusb-1.0.dylib",
        "/usr/local/opt/libusb/lib/libusb-1.0.dylib",
        "libusb-1.0.so.0",
    ]
    failures = []
    for candidate in candidates:
        if not candidate:
            continue
        try:
            return ctypes.CDLL(candidate)
        except OSError as exc:
            failures.append(f"{candidate}: {exc}")
    detail = "\n".join(failures)
    raise USBError(
        "找不到 libusb。请先执行 `brew install libusb`。"
        + (f"\n{detail}" if detail else "")
    )


class LibUSB:
    def __init__(self) -> None:
        self.lib = _load_libusb()
        self._declare()

    def _declare(self) -> None:
        lib = self.lib
        lib.libusb_init.argtypes = [ctypes.POINTER(ctypes.c_void_p)]
        lib.libusb_init.restype = ctypes.c_int
        lib.libusb_exit.argtypes = [ctypes.c_void_p]
        lib.libusb_exit.restype = None
        lib.libusb_open_device_with_vid_pid.argtypes = [
            ctypes.c_void_p,
            ctypes.c_uint16,
            ctypes.c_uint16,
        ]
        lib.libusb_open_device_with_vid_pid.restype = ctypes.c_void_p
        lib.libusb_close.argtypes = [ctypes.c_void_p]
        lib.libusb_close.restype = None
        lib.libusb_claim_interface.argtypes = [ctypes.c_void_p, ctypes.c_int]
        lib.libusb_claim_interface.restype = ctypes.c_int
        lib.libusb_release_interface.argtypes = [ctypes.c_void_p, ctypes.c_int]
        lib.libusb_release_interface.restype = ctypes.c_int
        lib.libusb_set_auto_detach_kernel_driver.argtypes = [
            ctypes.c_void_p,
            ctypes.c_int,
        ]
        lib.libusb_set_auto_detach_kernel_driver.restype = ctypes.c_int
        lib.libusb_control_transfer.argtypes = [
            ctypes.c_void_p,
            ctypes.c_uint8,
            ctypes.c_uint8,
            ctypes.c_uint16,
            ctypes.c_uint16,
            ctypes.POINTER(ctypes.c_ubyte),
            ctypes.c_uint16,
            ctypes.c_uint,
        ]
        lib.libusb_control_transfer.restype = ctypes.c_int
        lib.libusb_bulk_transfer.argtypes = [
            ctypes.c_void_p,
            ctypes.c_ubyte,
            ctypes.POINTER(ctypes.c_ubyte),
            ctypes.c_int,
            ctypes.POINTER(ctypes.c_int),
            ctypes.c_uint,
        ]
        lib.libusb_bulk_transfer.restype = ctypes.c_int
        lib.libusb_clear_halt.argtypes = [ctypes.c_void_p, ctypes.c_ubyte]
        lib.libusb_clear_halt.restype = ctypes.c_int
        lib.libusb_error_name.argtypes = [ctypes.c_int]
        lib.libusb_error_name.restype = ctypes.c_char_p

    def error_name(self, code: int) -> str:
        raw = self.lib.libusb_error_name(code)
        return raw.decode("ascii", errors="replace") if raw else str(code)


class CH347UART:
    """Minimal CH347T mode-3 UART transport for UART0."""

    def __init__(self, baud: int = UART_BAUD) -> None:
        self.usb = LibUSB()
        self.context = ctypes.c_void_p()
        self.handle = ctypes.c_void_p()
        self.claimed = False
        self._rx_buffer = bytearray()

        rc = self.usb.lib.libusb_init(ctypes.byref(self.context))
        self._check(rc, "初始化 libusb")
        handle = self.usb.lib.libusb_open_device_with_vid_pid(
            self.context, VID, PID
        )
        if not handle:
            self.close()
            raise USBError(
                "没有找到 CH347T（USB 1a86:55dd）。请确认板子已上电且 Type-C 已连接。"
            )
        self.handle = ctypes.c_void_p(handle)

        # Harmless on macOS; useful if another supported OS attached a driver.
        self.usb.lib.libusb_set_auto_detach_kernel_driver(self.handle, 1)
        rc = self.usb.lib.libusb_claim_interface(self.handle, UART_INTERFACE)
        self._check(rc, f"占用 CH347 UART 数据接口 {UART_INTERFACE}")
        self.claimed = True

        self.usb.lib.libusb_clear_halt(self.handle, UART_OUT_ENDPOINT)
        self.usb.lib.libusb_clear_halt(self.handle, UART_IN_ENDPOINT)
        self.configure_8n1(baud)

    def _check(self, code: int, operation: str) -> None:
        if code < LIBUSB_SUCCESS:
            name = self.usb.error_name(code)
            raise USBError(f"{operation}失败：{name} ({code})")

    def configure_8n1(self, baud: int) -> None:
        if baud <= 0 or baud > 6_000_000:
            raise ValueError("CH347 UART 波特率超出支持范围")

        # CH347TF high-speed divisor encoding from WCH's ch343 driver.
        # For 1,000,000 baud: divisor = 5000 = 0x1388.
        divisor = int(round(baud / 200.0))
        actual = divisor * 200
        if divisor > 0xFFFF or abs(actual - baud) / baud > 0.01:
            raise ValueError(f"CH347 无法在 1% 内产生 {baud} baud")
        factor = divisor & 0xFF
        divisor_high = (divisor >> 8) & 0xFF
        value = 0xC38C  # UART enabled, receiver enabled, 8 data, 1 stop, no parity
        # WCH places fct in the high byte and dvs in the low byte.
        # At 1 Mbaud this is therefore 0x8813, not 0x1388.
        index = (factor << 8) | divisor_high
        rc = self.usb.lib.libusb_control_transfer(
            self.handle,
            0x40,  # vendor, device, host-to-device
            0xA1,  # UART0 line configuration
            value,
            index,
            None,
            0,
            1000,
        )
        self._check(rc, f"设置 UART 为 {baud} baud 8N1")

    def write(self, data: bytes, timeout_ms: int = 1000) -> None:
        offset = 0
        while offset < len(data):
            chunk = data[offset : offset + 4096]
            buffer = (ctypes.c_ubyte * len(chunk)).from_buffer_copy(chunk)
            transferred = ctypes.c_int()
            rc = self.usb.lib.libusb_bulk_transfer(
                self.handle,
                UART_OUT_ENDPOINT,
                buffer,
                len(chunk),
                ctypes.byref(transferred),
                timeout_ms,
            )
            self._check(rc, "发送 UART 数据")
            if transferred.value <= 0:
                raise USBError("发送 UART 数据时没有传输任何字节")
            offset += transferred.value

    def read_some(self, size: int = 4096, timeout_ms: int = 1000) -> bytes:
        buffer = (ctypes.c_ubyte * size)()
        transferred = ctypes.c_int()
        rc = self.usb.lib.libusb_bulk_transfer(
            self.handle,
            UART_IN_ENDPOINT,
            buffer,
            size,
            ctypes.byref(transferred),
            timeout_ms,
        )
        if rc == LIBUSB_ERROR_TIMEOUT:
            return bytes(buffer[: transferred.value])
        self._check(rc, "接收 UART 数据")
        return bytes(buffer[: transferred.value])

    def read_exact(self, size: int, timeout_ms: int = 3000) -> bytes:
        deadline = time.monotonic() + timeout_ms / 1000.0
        while len(self._rx_buffer) < size:
            remaining_ms = max(1, int((deadline - time.monotonic()) * 1000))
            if time.monotonic() >= deadline:
                raise USBError(
                    f"等待数据超时（缓存中有 {len(self._rx_buffer)}/{size} 字节）"
                )
            # Always offer room for a complete high-speed USB packet. Asking
            # libusb for only the caller's remaining byte count can turn a
            # perfectly valid multi-byte response into LIBUSB_ERROR_OVERFLOW.
            chunk = self.read_some(4096, remaining_ms)
            if chunk:
                self._rx_buffer.extend(chunk)
        result = bytes(self._rx_buffer[:size])
        del self._rx_buffer[:size]
        return result

    def flush_input(self) -> None:
        self._rx_buffer.clear()
        for _ in range(16):
            if not self.read_some(4096, 10):
                break

    def close(self) -> None:
        if getattr(self, "handle", None) and self.handle.value:
            if self.claimed:
                self.usb.lib.libusb_release_interface(self.handle, UART_INTERFACE)
                self.claimed = False
            self.usb.lib.libusb_close(self.handle)
            self.handle = ctypes.c_void_p()
        if getattr(self, "context", None) and self.context.value:
            self.usb.lib.libusb_exit(self.context)
            self.context = ctypes.c_void_p()

    def __enter__(self) -> "CH347UART":
        return self

    def __exit__(self, exc_type, exc, traceback) -> None:
        self.close()


@dataclass(frozen=True)
class Frame:
    response_type: int
    status: int
    payload: bytes


def read_frame(transport: CH347UART, timeout_ms: int = 3000) -> Frame:
    """Read, resynchronise and validate one MCA response frame."""
    deadline = time.monotonic() + timeout_ms / 1000.0
    window = bytearray()
    while bytes(window) != MAGIC:
        remaining_ms = max(1, int((deadline - time.monotonic()) * 1000))
        if time.monotonic() >= deadline:
            raise ProtocolError("等待 MCA1 帧头超时")
        window.extend(transport.read_exact(1, remaining_ms))
        if len(window) > len(MAGIC):
            del window[0]

    rest = transport.read_exact(
        4, max(1, int((deadline - time.monotonic()) * 1000))
    )
    response_type, status, payload_length = struct.unpack("<BBH", rest)
    body = transport.read_exact(
        payload_length + 2,
        max(1, int((deadline - time.monotonic()) * 1000)),
    )
    payload = body[:-2]
    received_crc = struct.unpack("<H", body[-2:])[0]
    calculated_crc = crc16_ccitt(MAGIC + rest + payload)
    if received_crc != calculated_crc:
        raise ProtocolError(
            f"CRC 错误：收到 0x{received_crc:04x}，计算得 0x{calculated_crc:04x}"
        )
    return Frame(response_type, status, payload)


class MCADevice:
    def __init__(self, transport: CH347UART) -> None:
        self.transport = transport

    def command(
        self,
        request: bytes,
        expected_type: Optional[int] = None,
        timeout_ms: int = 3000,
    ) -> Frame:
        self.transport.flush_input()
        self.transport.write(request)
        frame = read_frame(self.transport, timeout_ms)
        if expected_type is not None and frame.response_type != expected_type:
            raise ProtocolError(
                f"响应类型错误：期望 0x{expected_type:02x}，收到 0x{frame.response_type:02x}"
            )
        if frame.status != 0:
            raise ProtocolError(f"设备返回错误状态 0x{frame.status:02x}")
        return frame

    def info(self) -> dict:
        payload = self.command(b"I", RESP_INFO).payload
        if len(payload) != 16:
            raise ProtocolError(f"INFO 长度错误：{len(payload)}")
        major, minor, adc_bits, features, sample_rate, channels, baud, _ = (
            struct.unpack("<BBBBIHIH", payload)
        )
        return {
            "version": f"{major}.{minor}",
            "adc_bits": adc_bits,
            "features": features,
            "sample_rate": sample_rate,
            "channels": channels,
            "baud": baud,
        }

    def stats(self) -> dict:
        payload = self.command(b"S", RESP_STATS).payload
        if len(payload) != 44:
            raise ProtocolError(f"STATS 长度错误：{len(payload)}")
        values = struct.unpack("<HHHHHBBIIIIIQHBB", payload)
        keys = (
            "sample",
            "baseline",
            "adc_min",
            "adc_max",
            "threshold",
            "polarity",
            "flags",
            "triggers",
            "accepted",
            "rejected",
            "saturated",
            "dropped",
            "live_samples",
            "last_peak",
            "uart_errors",
            "reserved",
        )
        return dict(zip(keys, values))

    def histogram(self) -> list[int]:
        payload = self.command(b"H", RESP_HIST, timeout_ms=5000).payload
        if len(payload) != 4096 * 4:
            raise ProtocolError(f"HIST 长度错误：{len(payload)}")
        return list(struct.unpack("<4096I", payload))

    def clear(self) -> None:
        self.command(b"C", 0xC3)

    def set_threshold(self, value: int) -> int:
        if not 0 <= value <= 4095:
            raise ValueError("阈值必须在 0..4095 道之间")
        frame = self.command(b"T" + struct.pack("<H", value), 0xD4)
        if len(frame.payload) != 4:
            raise ProtocolError("阈值确认帧长度错误")
        return struct.unpack_from("<H", frame.payload, 2)[0]

    def set_polarity(self, reverse: bool) -> int:
        frame = self.command(b"P" + bytes([int(reverse)]), 0xD0)
        if len(frame.payload) != 4:
            raise ProtocolError("极性确认帧长度错误")
        return struct.unpack_from("<H", frame.payload, 2)[0]


def save_histogram(path: Path, counts: Iterable[int]) -> None:
    path.parent.mkdir(parents=True, exist_ok=True)
    with path.open("w", newline="", encoding="utf-8") as handle:
        writer = csv.writer(handle)
        writer.writerow(("channel", "counts"))
        writer.writerows(enumerate(counts))


def print_info(info: dict) -> None:
    feature_names = []
    if info["features"] & 0x01:
        feature_names.append("峰高直方图")
    if info["features"] & 0x02:
        feature_names.append("4 点滑动平均")
    if info["features"] & 0x04:
        feature_names.append("2 点迟滞触发确认")
    if info["features"] & 0x08:
        feature_names.append("对称基线 IIR")
    if info["features"] & 0x10:
        feature_names.append("IOLOGIC ADC 下降沿采样")
    unknown_features = info["features"] & ~0x1F
    if unknown_features:
        feature_names.append(f"未知特性 0x{unknown_features:02x}")

    print(f"固件版本: {info['version']}")
    print(f"ADC: {info['adc_bits']} bit @ {info['sample_rate']:,} sample/s")
    print(f"谱道数: {info['channels']}")
    print(f"UART: {info['baud']:,} baud")
    print("算法特性: " + ("、".join(feature_names) if feature_names else "未报告"))


def print_stats(stats: dict) -> None:
    live_seconds = stats["live_samples"] / 10_000_000.0
    rate = stats["accepted"] / live_seconds if live_seconds else 0.0
    print(
        f"ADC 当前/基线/最小/最大: {stats['sample']} / {stats['baseline']} / "
        f"{stats['adc_min']} / {stats['adc_max']}"
    )
    print(
        f"阈值: {stats['threshold']}  极性: "
        f"{'负向（基线−采样）' if stats['polarity'] else '正向（采样−基线）'}"
    )
    print(
        f"触发/接受/拒绝/饱和/丢失: {stats['triggers']} / {stats['accepted']} / "
        f"{stats['rejected']} / {stats['saturated']} / {stats['dropped']}"
    )
    print(f"有效采集时间: {live_seconds:.3f} s  平均计数率: {rate:.3f} cps")
    print(f"最近峰值道: {stats['last_peak']}  UART 帧错误: {stats['uart_errors']}")


def default_output_path() -> Path:
    stamp = datetime.now().strftime("%Y%m%d-%H%M%S")
    return Path(f"aster-mca-spectrum-{stamp}.csv")


def build_parser() -> argparse.ArgumentParser:
    parser = argparse.ArgumentParser(
        description="Aster MCA v1：通过板载 CH347T 在 macOS 直接读谱"
    )
    sub = parser.add_subparsers(dest="command", required=True)
    sub.add_parser("info", help="读取固件与 ADC 信息")
    sub.add_parser("stats", help="读取实时状态和计数率")
    sub.add_parser("clear", help="清空谱和统计计数")

    threshold = sub.add_parser("threshold", help="设置触发阈值（ADC 道）")
    threshold.add_argument("value", type=int)

    polarity = sub.add_parser("polarity", help="设置 ADC 脉冲方向")
    polarity.add_argument(
        "mode", choices=("negative", "positive", "default", "reverse")
    )

    spectrum = sub.add_parser("spectrum", help="立即读取当前 4096 道谱")
    spectrum.add_argument("-o", "--output", type=Path, default=None)

    acquire = sub.add_parser("acquire", help="清空后采集指定时间并保存谱")
    acquire.add_argument("seconds", type=float)
    acquire.add_argument("-o", "--output", type=Path, default=None)
    acquire.add_argument(
        "--threshold", type=int, default=None, help="开始前设置触发阈值"
    )
    return parser


def run(args: argparse.Namespace) -> int:
    with CH347UART() as transport:
        device = MCADevice(transport)
        if args.command == "info":
            print_info(device.info())
        elif args.command == "stats":
            print_stats(device.stats())
        elif args.command == "clear":
            device.clear()
            print("谱和统计计数已清空。")
        elif args.command == "threshold":
            actual = device.set_threshold(args.value)
            print(f"阈值已设为 {actual} 道。")
        elif args.command == "polarity":
            # Keep the old aliases for compatibility: reverse == negative,
            # default == positive.  New scripts should use explicit names.
            actual = device.set_polarity(args.mode in ("negative", "reverse"))
            print("极性已设为" + ("负向。" if actual else "正向。"))
        elif args.command == "spectrum":
            output = args.output or default_output_path()
            counts = device.histogram()
            save_histogram(output, counts)
            print(f"已保存 {sum(counts)} 个事件到 {output.resolve()}")
        elif args.command == "acquire":
            if args.seconds <= 0:
                raise ValueError("采集时间必须大于 0 秒")
            if args.threshold is not None:
                actual = device.set_threshold(args.threshold)
                print(f"阈值已设为 {actual} 道。")
            device.clear()
            print(f"开始采集 {args.seconds:g} 秒……")
            deadline = time.monotonic() + args.seconds
            while True:
                remaining = deadline - time.monotonic()
                if remaining <= 0:
                    break
                time.sleep(min(1.0, remaining))
            stats = device.stats()
            counts = device.histogram()
            output = args.output or default_output_path()
            save_histogram(output, counts)
            print_stats(stats)
            print(f"已保存 {sum(counts)} 个事件到 {output.resolve()}")
    return 0


def main() -> int:
    parser = build_parser()
    try:
        return run(parser.parse_args())
    except (AsterMCAError, OSError, ValueError) as exc:
        print(f"错误：{exc}", file=sys.stderr)
        return 1


if __name__ == "__main__":
    raise SystemExit(main())

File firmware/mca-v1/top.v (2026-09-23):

module top (
    input  wire        clk_10mhz,
    input  wire [11:0] adc_data,
    input  wire        uart_rx_pin,
    output wire        uart_tx_pin,
    output wire        adc_pd,
    output wire        status_led,
    output wire        trig_out
);
    localparam [2:0] TX_IDLE    = 3'd0;
    localparam [2:0] TX_HEADER  = 3'd1;
    localparam [2:0] TX_PAYLOAD = 3'd2;
    localparam [2:0] TX_CRC_LO  = 3'd3;
    localparam [2:0] TX_CRC_HI  = 3'd4;

    localparam [1:0] CMD_IDLE   = 2'd0;
    localparam [1:0] CMD_T_LO   = 2'd1;
    localparam [1:0] CMD_T_HI   = 2'd2;
    localparam [1:0] CMD_POL    = 2'd3;

    localparam [7:0] RESP_INFO  = 8'h49; // I
    localparam [7:0] RESP_STATS = 8'h53; // S
    localparam [7:0] RESP_HIST  = 8'h48; // H

    reg [7:0] reset_count = 8'd0;
    wire rst = !reset_count[7];
    always @(posedge clk_10mhz)
        if (!reset_count[7])
            reset_count <= reset_count + 1'b1;

    // ADC12010 updates after the rising edge. Capture every bit on the falling
    // edge in its dedicated IOLOGIC cell. Q1 is the falling-edge sample and is
    // presented to the fabric on the following rising edge. Keeping this first
    // register in the I/O cell prevents placement-dependent bus skew.
    wire [11:0] adc_sample_rising_unused;
    wire [11:0] adc_sample_iddr;
    genvar adc_bit;
    generate
        for (adc_bit = 0; adc_bit < 12; adc_bit = adc_bit + 1) begin : adc_input
            IDDR adc_iddr (
                .D(adc_data[adc_bit]),
                .CLK(clk_10mhz),
                .Q0(adc_sample_rising_unused[adc_bit]),
                .Q1(adc_sample_iddr[adc_bit])
            );
        end
    endgenerate

    // IDDR Q1 is transferred into the rising-edge domain at the clock edge.
    // This extra stage consumes the already-stable value on the next edge and
    // gives every bit a full 100 ns cycle for IOLOGIC-to-fabric routing.
    reg [11:0] adc_sample = 12'd2048;
    always @(posedge clk_10mhz)
        adc_sample <= adc_sample_iddr;

    assign adc_pd = 1'b0;

    reg [11:0] threshold = 12'd32;
    // The assembled analog path produces negative-going ADC codes for the
    // user's amplified PMT module.  1 selects baseline-sample.
    reg polarity = 1'b1;
    reg clear_stats_request = 1'b0;
    reg hist_clear_request = 1'b0;
    reg stream_pause = 1'b0;

    wire event_valid;
    wire [11:0] event_bin;
    wire trigger_pulse;
    wire [11:0] current_sample;
    wire [11:0] baseline;
    wire [11:0] adc_min;
    wire [11:0] adc_max;
    wire [11:0] last_peak;
    wire pulse_active;
    wire [31:0] trigger_count;
    wire [31:0] accepted_count;
    wire [31:0] rejected_count;
    wire [31:0] saturated_count;
    wire [63:0] live_samples;

    wire hist_ready;
    wire [31:0] hist_dropped_events;
    reg [11:0] hist_read_address = 12'd0;
    wire [31:0] hist_read_data;

    wire acquisition_enable = hist_ready && !stream_pause;

    mca_engine engine (
        .clk(clk_10mhz),
        .rst(rst),
        .enable(acquisition_enable),
        .clear_stats(clear_stats_request),
        .sample(adc_sample),
        .threshold(threshold),
        .polarity(polarity),
        .event_valid(event_valid),
        .event_bin(event_bin),
        .trigger_pulse(trigger_pulse),
        .current_sample(current_sample),
        .baseline(baseline),
        .adc_min(adc_min),
        .adc_max(adc_max),
        .last_peak(last_peak),
        .pulse_active(pulse_active),
        .trigger_count(trigger_count),
        .accepted_count(accepted_count),
        .rejected_count(rejected_count),
        .saturated_count(saturated_count),
        .live_samples(live_samples)
    );

    histogram spectrum (
        .clk(clk_10mhz),
        .rst(rst),
        .clear_request(hist_clear_request),
        .event_valid(event_valid),
        .event_bin(event_bin),
        .read_address(hist_read_address),
        .read_data(hist_read_data),
        .ready(hist_ready),
        .dropped_events(hist_dropped_events)
    );

    wire [7:0] uart_rx_data;
    wire uart_rx_valid;
    wire uart_framing_error;
    uart_rx #(.CLKS_PER_BIT(10)) receiver (
        .clk(clk_10mhz),
        .rst(rst),
        .rx(uart_rx_pin),
        .data(uart_rx_data),
        .valid(uart_rx_valid),
        .framing_error(uart_framing_error)
    );

    // Only the low byte is reported. Keeping this counter at its actual width
    // avoids a partially-unused wide register that older nextpnr-gowin builds
    // can leave behind as an unplaceable generic $buf cell.
    reg [7:0] uart_error_count = 8'd0;
    always @(posedge clk_10mhz)
        if (rst)
            uart_error_count <= 8'd0;
        else if (uart_framing_error)
            uart_error_count <= uart_error_count + 1'b1;

    reg [2:0] tx_state = TX_IDLE;
    reg [2:0] header_index = 3'd0;
    reg [15:0] payload_index = 16'd0;
    reg [15:0] payload_length = 16'd0;
    reg [7:0] response_type = 8'h00;
    reg [7:0] response_status = 8'h00;
    reg [15:0] response_crc = 16'hffff;

    reg [7:0] ack_command = 8'h00;
    reg [15:0] ack_value = 16'h0000;
    reg [1:0] command_state = CMD_IDLE;
    reg [7:0] threshold_low = 8'h00;

    // Snapshot registers keep a statistics response internally consistent.
    reg [11:0] snap_sample = 12'd0;
    reg [11:0] snap_baseline = 12'd0;
    reg [11:0] snap_min = 12'd0;
    reg [11:0] snap_max = 12'd0;
    reg [11:0] snap_threshold = 12'd0;
    reg snap_polarity = 1'b0;
    reg [7:0] snap_flags = 8'h00;
    reg [31:0] snap_triggers = 32'd0;
    reg [31:0] snap_accepted = 32'd0;
    reg [31:0] snap_rejected = 32'd0;
    reg [31:0] snap_saturated = 32'd0;
    reg [31:0] snap_dropped = 32'd0;
    reg [63:0] snap_live = 64'd0;
    reg [11:0] snap_last_peak = 12'd0;

    function [15:0] crc16_next;
        input [15:0] crc_in;
        input [7:0] byte_in;
        integer bit_number;
        reg [15:0] work;
        begin
            work = crc_in ^ {byte_in, 8'h00};
            for (bit_number = 0; bit_number < 8; bit_number = bit_number + 1)
                if (work[15])
                    work = (work << 1) ^ 16'h1021;
                else
                    work = work << 1;
            crc16_next = work;
        end
    endfunction

    function [7:0] select_u32_byte;
        input [31:0] value;
        input [1:0] byte_number;
        begin
            case (byte_number)
                2'd0: select_u32_byte = value[7:0];
                2'd1: select_u32_byte = value[15:8];
                2'd2: select_u32_byte = value[23:16];
                default: select_u32_byte = value[31:24];
            endcase
        end
    endfunction
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

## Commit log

2026-09-21 Initial public release of Aster MCA
    [BOM-readable.tsv, Pin-net-reference.csv, assembly-overrides.csv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]
2026-09-25 Publish Aster MCA v2.0 r8 hardware concept
    [Aster-MCA-v2.0-B_Cu.gbr, Aster-MCA-v2.0-B_Mask.gbr, Aster-MCA-v2.0-B_Paste.gbr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]
